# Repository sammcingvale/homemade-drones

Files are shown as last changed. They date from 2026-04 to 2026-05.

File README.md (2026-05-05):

# homemade-drones

at-home, at-scale drone swarms. drones, lots of drones.

## repo layout

```
drone-program/
├── docs/                    # cross-build documentation
│   ├── design-principles.md
│   ├── safety-checklist.md
│   └── repo-conventions.md
├── tools/                   # scripts shared across builds
├── hardware-library/        # reusable parts catalog, kits, CAD
│   ├── parts-catalog/       # abstract part specs + ranked SKUs + reorder guidance
│   └── kits/                # packing lists for field/bench operations
└── builds/
    ├── v1/                  # build #1 — learning vehicle, fly ASAP
    │   ├── README.md        # build summary + status
    │   ├── requirements.md  # frozen requirements doc for this build
    │   ├── bom.md           # bill of materials (references catalog by cat-NNN)
    │   ├── tooling.md       # tools required to assemble
    │   ├── cad/             # 3D models — one folder per part
    │   ├── firmware/        # ArduCopter firmware + parameters
    │   ├── assembly/        # assembly notes + build photos
    │   ├── flight-logs/     # per-flight logs and post-flight notes
    │   └── post-mortem.md   # written after build is retired
    ├── v2/                  # (future)
    └── v3/                  # (future)
```

## build status

| build | goal | status | flight count |
|---|---|---|---|
| v1 | L1 autonomy — GPS waypoint mission | 🟡 in design | 0 |
| v2 | L1+ — geofence, optical-flow position hold | ⚪ not started | — |
| v3 | L2 — vision-based autonomy, GPS-denied | ⚪ not started | — |
| v4 | L3 — swarm coordination | ⚪ not started | — |

## per-build philosophy

each `builds/vN/` folder is a complete, self-contained snapshot of that drone build. requirements, BOM, CAD, firmware, and flight logs live with the build they belong to. when v2 starts, we copy v1's contents as a starting point and iterate — old builds stay frozen for reference and post-mortem analysis.

components that prove themselves across multiple builds graduate to `hardware-library/`.

## getting started

if you're cloning fresh:
1. read `docs/design-principles.md` and `docs/safety-checklist.md`.
2. open the most recent active build's `README.md` for current status.
3. never skip a gate in the test plan. failed gate → debug, don't push through.

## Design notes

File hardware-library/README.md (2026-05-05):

# hardware-library/

Cross-build hardware design knowledge: parts catalog, kits, and (eventually) reusable CAD components.

## Subfolders

```
hardware-library/
├── parts-catalog/    # Abstract part specs + ranked SKU lists + reorder guidance
├── kits/             # Packing lists for field/bench operations
└── (cad/)            # Reusable CAD components — populated when parts graduate from a build
```

## What lives here vs. what doesn't

This folder holds **design knowledge** that spans builds: which parts are acceptable, why we picked them, what they're for. It's version-controlled, infrequently mutated, and tied to the project.

It deliberately does **not** hold operational state — current on-hand counts, order history, who-touched-what-when. Those live outside the repo and are owned by tooling that operates across multiple projects.

## Catalog vs. BOM

- **Catalog** (`parts-catalog/`): "what parts are acceptable for builds in this project, ranked by preference."
- **BOM** (`builds/vN/bom.md`): "what was procured for this specific build, at what price, on what date."

A build's BOM references catalog entries by ID. The catalog is the abstract spec; the BOM is the concrete procurement record for one build.

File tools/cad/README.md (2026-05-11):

# CAD toolchain

We use [CadQuery](https://cadquery.readthedocs.io/) (Python) for parametric models. `.py` files are the source of truth; STEP and STL are exported artifacts.

## Why CadQuery

- Plain-text source → diff-friendly, branch-mergeable, AI-editable.
- Parametric: every part exposes a single block of variables at the top of its `.py`.
- Free, no account, no licence keys.
- STEP export is reusable in Fusion 360 / OnShape / FreeCAD if a part graduates to a more complex workflow later.

## One-time setup

CadQuery's OCP backend needs Python 3.11. The repo root keeps a venv at `.venv/`.

```bash
# from the repo root
uv venv --python 3.11 .venv
uv pip install --python .venv/bin/python -r tools/cad/requirements.txt
```

`.venv/` is gitignored.

## Generating exports

Each part's `.py` is runnable directly. From the repo root:

```bash
.venv/bin/python builds/v1/cad/gps-mast/gps-mast-v1.py
```

The script writes `*.step` and `*.stl` next to itself. Re-run after any geometry edit.

## What gets committed

| Committed | Source / generated |
|---|---|
| `<part>-v<n>.py` | source — hand-edited |
| `<part>-v<n>.step` | generated — kept in git so reviewers don't need a Python env |
| `<part>-v<n>.stl` | generated — convenience export |
| `<part>-v<n>.3mf` | generated in Bambu Studio with slicer profile baked in |
| `<part>-v<n>.slicer-profile.json` | exported from Bambu Studio after tuning |
| `README.md`, `notes.md` | hand-written |

`.3mf` and the slicer profile come from Bambu Studio, not the Python script — they capture print settings, not just geometry.

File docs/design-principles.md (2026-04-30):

# design principles

cross-build principles that apply to every drone build.

## scaled-manufacturing posture (from v1)

even though v1 is a learning vehicle, we bake in habits that scale.

- **no exotic sourcing.** every part available from ≥2 distributors. eventually target US-based distributors and vertically integrated where possible.
- **no hand-tuned firmware per unit.** firmware flash is a script. parameters are version-controlled per airframe revision, not per serial number.
- **print times scale.** no part exceeds 4h on a stock 0.4mm nozzle.
- **standard fasteners.** M3 for structure, M2 for electronics. single thread pitch only.
- **connector discipline.** XT60 battery, MR30 / PH 2.0 accessories, ELRS-standard pinout receiver.
- **replaceable wear items.** props, motors, FC swappable in <10 min field repair.
- **identical units.** two airframes of the same revision must be functionally interchangeable.

## build progression philosophy

| build | bias |
|---|---|
| v1 | **fly ASAP.** hybrid (purchased CF + printed accessories). standard parts, well-documented stack. |
| v2 | **iterate on print.** move structural parts to printed PA-CF. tighten assembly time. |
| v3 | **add autonomy depth.** companion computer, vision stack, GPS-denied. |
| v4 | **multiply.** swarm comms, coordination. optimize manufacturability. |

## test gating discipline

every build runs through the same 10 gates (G1–G10). a failed gate is always a debug step, never a "we'll fix it later."

## versioning

- requirements doc: `requirements.md` per build, with a `## changelog` section at the bottom.
- CAD: `/cad/<part>/v<n>/` — increment `n` for any geometry change. old versions stay.
- firmware params: `/firmware/params/<airframe_serial>.params` — committed before each flight.
- flight logs: `/flight-logs/<YYYY-MM-DD>_<flight_id>/` — bin file, telemetry, post-flight notes.

## decision logs

substantive design decisions get logged. format: short markdown file in `/docs/decisions/` titled `NNNN-decision-name.md` with date, context, options considered, decision, consequences. inspired by ADRs (Architecture Decision Records).

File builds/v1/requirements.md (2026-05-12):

# Drone Requirements — v1 build

**Version:** v0.3
**Status:** LOCKED for parts ordering
**Build target:** v1 (learning vehicle)
**Constraint:** flight-capable in <7 days from parts arrival
**Long-term:** scaled printing + assembly of identical units, eventually swarm-coordinated

---

## 0. Locked decisions

| # | Decision | Value | Status |
|---|---|---|---|
| 0.1 | Frame size (prop diameter) | 5" | LOCKED |
| 0.2 | Sub-250g target? | No (v1). Will target lower weights in subsequent builds. | LOCKED |
| 0.3 | Indoor / outdoor / both | Outdoor, GPS-available | LOCKED |
| 0.4 | Structural main plate | Purchased CF (Source One V5). Print accessories. | LOCKED |
| 0.5 | Autonomy scope for v1 | L1 — GPS waypoint mission (see §2.5) | LOCKED |
| 0.6 | Companion computer in v1? | No — defer to v3 | LOCKED |
| 0.7 | Onboard pilot-view video link? | **No, in any build.** Cameras allowed only for autonomy/mission data inputs. | LOCKED |
| 0.8 | FC firmware | ArduCopter (latest stable, ≥4.5) | LOCKED |
| 0.9 | Ground station | Mission Planner on Windows (used Toughbook CF-54) | LOCKED |
| 0.10 | Radio (TX) | RadioMaster Pocket (ELRS built-in) | LOCKED |
| 0.11 | Number of airframes for week 1 | 1 | LOCKED |
| 0.12 | Jurisdiction | US (FAA) | LOCKED |

---

## 1. Design principles

See `docs/design-principles.md` for cross-build principles. Build-specific notes:

- v1 prioritizes **time-to-flight** over manufacturability or performance.
- v1 uses standard, well-documented components so help is one Google query away.
- v1 builds the workflow: order → assemble → flash → bench-test → tethered → free flight → autonomous. Same workflow scales to v2+.

---

## 2. Mission profile

| Parameter | Value | Notes |
|---|---|---|
| Operating environment | Outdoor, open field, daylight | Park adjacent to operator |
| GPS available | Yes | Drives autonomy stack |
| Operating altitude (AGL) | <120m (US Part 107 ceiling) | v1 mission flies at 5m |
| Range from operator | <500m line-of-sight | ELRS easily covers |
| Endurance per sortie | 8–12 min hover max | Sets battery sizing |
| Mission payload (carried) | None | LOCKED |
| Speed envelope | 0–20 m/s typical | v1 mission flies at 2 m/s |
| Wind tolerance | <8 m/s sustained | Hard ceiling on 5" airframe |
| Weather | Dry only | No conformal coating in v1 |
| Day/night | Day only | No nav lights in v1 |
| Temperature | 0°C to 35°C ambient | LiPo limits |

**v2+ deferred:** rain/dust ingress, night ops, BVLOS, cold-soak, payload drop.

---

## 2.5 Autonomy roadmap

| Build | Level | Capability | Stack additions |
|---|---|---|---|
| **v1** | **L1 — Pre-programmed mission** | **GPS waypoint mission, manual abort, auto RTH on failsafe** | **ArduCopter AUTO mode, Mission Planner mission upload** |
| v2 | L1+ | Geofence, smart RTH, optical-flow position hold | + downward optical flow sensor |
| v3 | L2 — Reactive | Obstacle avoidance, GPS-denied hover (VIO), dynamic re-plan | + companion computer (RPi 5 / Jetson Orin Nano), ROS2, depth camera |
| v4 | L3 — Multi-vehicle | Swarm: formation, leader-follow, distributed task allocation | + mesh comms, ROS2 DDS, coordination logic |

### v1 mission spec

- **Pattern:** 4-waypoint square, 18m × 18m (≈ 20 yd × 20 yd)
- **Altitude:** 5m AGL, constant
- **Cruise speed:** 2 m/s (slow, observable, easy to abort)
- **Sequence:** Manual arm → AUTO-takeoff to 5m → WP1→WP2→WP3→WP4 (CCW from takeoff) → AUTO-RTH → AUTO-land
- **Total flight time:** ~90s

### v1 failsafe matrix

| Trigger | Response |
|---|---|
| RC link loss | RTH, then land |
| Battery <30% | RTH |
| Battery <20% | Land at current position |
| GPS loss >5s | Land at current position |
| Geofence breach | RTH to fence center |
| Pilot kill switch | Disarm immediately (motors stop) |

Failsafes configured in ArduCopter parameters (`firmware/params/v1-001.params`) and version-controlled.

---

## 3. Vehicle spec

| Slot | Spec |
|---|---|
| Class | Quadcopter, X-config |
| Frame | Source One V5 5" Base Kit |
| Motor-to-motor diagonal | 220mm |
| AUW target | 600–700g w/ 4S 1500mAh |
| AUW max (structural) | 900g |
| FC stack mounting | 30.5×30.5mm |

---

## 4. Propulsion

| Slot | Spec | Selection |
|---|---|---|
| Motors | 2207, ~1950KV (4S) | EMAX ECO II 2207 1900KV ×4 |
| Props | 5×4.3×3 (5-inch tri-blade) | HQProp T5x4.3x3 ×4 sets |
| ESC | 4-in-1, 55A, BLHeli_S | Bundled with FC stack |

Any 2207 motor in 1750–2000KV works. EMAX ECO II picked for cost + ubiquity. Don't agonize.

---

## 5. Power

| Slot | Spec | Selection |
|---|---|---|
| Chemistry | LiPo | |
| S-count | 4S | |
| Capacity | 1500 mAh | ~10 min hover |
| C-rating | 100C | |
| Connector | XT60 | |
| Charger | ToolkitRC M7 (built-in AC) | |
| Storage | LiPo bag, 3.8V/cell storage charge | |
| Field kit | 4× packs minimum | |

---

## 6. Avionics

| Slot | Spec | Selection | Notes |
|---|---|---|---|
| Flight controller + ESC | F4/H7 stack, 30.5×30.5mm | Holybro Kakute H7 v1.5 + Tekko32 F4 50A ESC | ArduCopter target `KakuteH7` (4.2.0+). SpeedyBee F405 V4 was the original choice; flipped 2026-05-11 after it went OOS at all distributors. |
| FC firmware | ArduCopter ≥4.5 | | Board ships with Betaflight — first flash via DFU |
| IMU | ICM-42688P | Onboard FC | |
| Barometer | Onboard FC | | |
| Magnetometer | External (on GPS module) | Bundled with M10Q-5883 GPS | NEVER use FC-internal mag |
| GPS + compass | u-blox M10 + QMC5883L | Matek M10Q-5883 | Mount on printed mast ≥80mm |
| Current/voltage sensor | Onboard ESC | | Required for ArduPilot battery failsafe |

**EMI / RF notes:**
- GPS mast ≥80mm. Non-negotiable.
- Magnetometer ≥150mm from high-current wires (mast-mounted solves this).
- ELRS RX antennas at 90° to each other, both extending past frame edges.
- Carbon fiber blocks RF — antennas must clear the frame in line-of-sight to operator.

---

## 7. Comms

| Link | Purpose | Selection | Range |
|---|---|---|---|
| RC control | Pilot input, failsafe | RadioMaster Pocket (ELRS) ↔ BetaFPV ELRS Lite RX | 2km+ |
| Telemetry | MAVLink ↔ Mission Planner | Holybro SiK Radio 915MHz pair | 1km+ |
| Video | **Not installed** | — | — |
| Swarm mesh | **Deferred to v4** | — | — |

---

## 8. Manufacturing — print plan

### v1 printed parts

| Part | Filament | Print time | Notes |
|---|---|---|---|
| Canopy / top plate | PETG | ~2h | Houses GPS, RX, telem |
| GPS mast (≥80mm) | PETG | ~30min | RF-transparent |
| Antenna mounts (×2) | TPU 95A | ~20min ea | Soft, won't snap |
| Battery tray + strap loop | PETG | ~1h | |
| Motor soft-mounts (×4) | TPU 95A | ~30min total | IMU vibration isolation |
| Standoffs (M3, ×4) | TPU 95A or aluminum | ~15min | Either works |

**Total print time: ~5h** on a Bambu P2S, single bed plate.

### Filament strategy

| Filament | Use case | v1 Required |
|---|---|---|
| **PETG** | Non-structural rigid parts | ✅ |
| **TPU 95A** | Soft mounts, antenna tubes | ✅ |
| **PA-CF** | Structural (v2+) | ❌ |
| **ASA** | Outdoor exposed parts (v2+) | ❌ |
| **PLA** | ❌ Do not use | ❌ |

### Printer config

- Bambu Lab P2S, AMS 2 Pro
- Stock 0.4mm nozzle for v1 (PETG + TPU only)
- Hardened nozzle deferred until v2 (when PA-CF enters)

### Print process discipline

- All parts version-controlled under `cad/<part>/` per repo conventions.
- STEP is source of truth. STL/3MF exported from STEP.
- Slicer profile committed alongside model.
- Print orientation noted in `notes.md` per part.
- No supports on production parts — design them out.

---

## 9. Regulatory & safety

US, FAA jurisdiction.

| Item | Requirement | Status |
|---|---|---|
| FAA recreational registration | Required >250g | ✅ Completed 2026-05-11 |
| Remote ID | Required >250g since Sept 2023 | ArduPilot built-in broadcast |
| Part 107 | Commercial only | Not needed |
| Flight area | TRUST cert + Class G airspace | ✅ TRUST completed 2026-05-11; airspace verified per flight |
| LAANC | Controlled airspace only | Avoid for v1 |
| Insurance | Optional | AMA membership recommended |

Safety procedures: see `docs/safety-checklist.md`.

---

## 10. Test plan — gates

Each gate must pass before next attempted. Failed gate → debug, don't push through.

| Gate | Pass criterion | Tools | Estimated day |
|---|---|---|---|
| G1: Bench power-on | FC boots, no smoke, no overheat | Smoke stopper, IR thermometer | Day 4 |
| G2: RX bind + arming | All channels move correctly, arming gate passes | Mission Planner | Day 4 |
| G3: Motor direction + ESC cal | All 4 motors spin correct direction, DSHOT telem healthy | Props OFF | Day 5 |
| G4: IMU + compass cal | Cal completes, mag interference <30% | MP cal screens | Day 5 |
| G5: GPS lock | ≥10 sats, HDOP <1.5, position holds within 2m at rest | Open sky, 5+ min | Day 5 |
| G6: Tethered hover | Stable hover, no oscillation, throttle response linear | 2m tether to ground anchor | Day 6 |
| G7: Free hover (manual STABILIZE) | 30s stable hover at 2m, manual landing | Open field, observer | Day 6 |
| G8: GPS position hold (LOITER) | Holds within 3m for 60s | | Day 6 |
| G9: RTH test | Triggers RTH, returns within 5m of takeoff, lands | Manual abort ready | Day 7 |
| **G10: AUTO mission** | **4-waypoint 18m square, autonomous start to finish** | **MP mission upload** | Day 7 |

**G10 = week-1 target.** See `bom.md` for parts and `tooling.md` for required tools.

---

## 11. v2+ deferred items

Cataloged so we don't lose them.

- Printed structural main plate + arms in PA-CF
- Conformal coating for moisture resistance
- Companion computer (RPi 5 / Jetson Orin Nano) for vision-based autonomy
- VIO / SLAM stack (ROS2 + PX4 / ArduPilot + VINS-Fusion)
- Obstacle avoidance sensors (ToF, depth camera)
- Mesh comms for swarm
- Multi-vehicle coordination
- Night ops
- Payload mounts / data collection
- Field-swappable battery (tool-less)
- Production jig for assembly time-tracking

---

## 12. Bill of materials

See `bom.md` (in this folder).

---

## 13. Tooling

See `tooling.md` (in this folder).

---

## Changelog

- **v0.3** — Locked all open decisions from Section 13. Added 0.7 (no pilot-view video, ever), 0.8–0.12 (firmware, ground station, radio, build count, jurisdiction). Specified concrete SKUs in §4–§7. Added day-by-day estimates to test plan. Author: Claude. Status: LOCKED.
- **v0.2** — Added §2.5 autonomy roadmap, v1 mission spec, failsafe matrix. Locked 0.5. Removed crash-survivability driver.
- **v0.1** — Initial draft.

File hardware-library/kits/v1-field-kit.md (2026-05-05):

# v1 Field Kit

What to bring to a field flight session with the v1 airframe.

## Aircraft + power

- [ ] v1 airframe (1×)
- [ ] LiPo packs, charged: 4× (cat-008)
- [ ] Spare LiPo: +1× if available
- [ ] LiPo bag (transport)
- [ ] Battery straps: 2× spare

## Spare parts (for in-field repair)

- [ ] Spare props: 8× individual props (cat-004) — 2 full sets
- [ ] Spare motor: 1× (cat-003)
- [ ] Spare M3 SHCS, 12mm + 16mm: ~10 each (cat-011)
- [ ] Spare M3 nyloc nuts: ~10 (cat-012)

## Tools (mechanical)

- [ ] 2.5mm hex driver (Wera)
- [ ] M5 nut driver / rubber prop wrench
- [ ] Side cutters
- [ ] Tweezers
- [ ] Loctite 243 (small bottle for motor screw replacement)

## Tools (electrical / diagnostic)

- [ ] Multimeter
- [ ] USB cable (USB-C, for FC reflash if needed)
- [ ] Smoke stopper (XT60 inline) — for any post-crash power-up

## Ground station

- [ ] Toughbook (charged)
- [ ] SiK ground radio (915MHz USB-A)
- [ ] USB-A extension cable
- [ ] RadioMaster Pocket transmitter (charged)
- [ ] USB-C cable for TX charging (optional, for long sessions)

## Safety + admin

- [ ] FAA registration card (or printout)
- [ ] TRUST certificate (printout or phone screenshot)
- [ ] Phone with B4UFLY app
- [ ] Sand bucket or fire extinguisher (Class D)
- [ ] First aid kit (small)
- [ ] Eye protection (cheap safety glasses)
- [ ] Sunshade for laptop (folding cardboard works fine)

## Logging

- [ ] Notebook + pen for in-field observations
- [ ] Phone for build/flight photos

---

## Pack-out workflow

Before leaving the workshop:

1. Charge all LiPos to **flight charge** (4.20V/cell). Confirm cell balance ≤0.02V deviation per pack.
2. Run the airframe through the safety checklist (`docs/safety-checklist.md` → Pre-flight).
3. Check the weather. <8 m/s sustained wind is the hard ceiling.
4. Verify flight area on B4UFLY.
5. Pack this kit. Tick boxes physically.

## Pack-in workflow

After returning from the field:

1. Set all LiPos to storage charge (3.80V/cell) within 24 hours.
2. Visual inspection of airframe — log any damage in build's `flight-logs/<latest>/notes.md`.
3. Note anything used or damaged in the field for follow-up restocking.
4. Note any tools left at the field site (it happens).

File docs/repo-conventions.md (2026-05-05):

# Repo Conventions

Lightweight rules so that files end up in predictable places.

## Naming

- Files and folders: lowercase, hyphenated. `gps-mast`, not `GPS_Mast` or `gpsMast`.
- Markdown extensions: `.md`.
- CAD: `<part>-v<n>.step`, `<part>-v<n>.3mf`. STEP is the source of truth; export STL/3MF from STEP.
- Slicer profiles: `<part>-v<n>.slicer-profile.json` next to the model.
- Firmware params: `<airframe-serial>.params` (e.g. `v1-001.params`).
- Flight logs: `<YYYY-MM-DD>_<flight-id>_<short-description>/` (e.g. `2025-12-04_001_first-tethered-hover/`).

## CAD versioning

For every printed part:
```
builds/v1/cad/<part-name>/
├── README.md                    # what the part does, design intent
├── <part-name>-v1.step          # source of truth
├── <part-name>-v1.3mf           # slicer-ready (with profile baked in)
├── <part-name>-v1.stl           # exported, optional
├── <part-name>-v1.slicer-profile.json
└── notes.md                     # print orientation, supports, lessons
```

Increment version on any geometry change. **Never edit a versioned file in place** — copy to v2 and edit there.

## Commits

- Imperative, present tense: "add v1 GPS mast STEP", not "added" or "adds".
- Reference the build in the subject if scoped to one: `[v1] update bom — switch to T-Motor F40`.
- One logical change per commit. Don't bundle "fix typo" with "redesign canopy".

## Branches

- `main` is always known-good. Pushing broken code there delays the next flight.
- Work on `vN/<short-feature>` branches. Merge to main when the change has been validated (printed and fitted, or flashed and tested).

## Catalog entries

`hardware-library/parts-catalog/cat-NNN-name.md` files follow the format documented in `hardware-library/parts-catalog/README.md`. Key rules:

- `cat-NNN` IDs are immutable. Don't renumber.
- A catalog entry is design knowledge: abstract spec, ranked SKUs, reorder guidance, last-known prices.
- Update `Last verified` whenever prices or SKU rankings change.

## What to commit, what not to

| Commit | Don't commit |
|---|---|
| STEP, 3MF, slicer profile | Slicer scratch files, autosaves |
| Firmware `.apj` actually flashed (under `firmware/flashed/`) | Random `.hex` downloads |
| Param files used for flight | Mission Planner cache |
| Flight log `.csv` and `.tlog` | Raw `.bin` files (>10MB; large + recoverable from .csv) |
| Build photos in `assembly/photos/` | Anything containing API keys, GPS home coords for your house |

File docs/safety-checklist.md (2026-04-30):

# safety checklist

read before every assembly session and every flight session. violation of any rule = stop work.

## workshop / assembly

- [ ] smoke stopper between battery and PDB on first power-up of any airframe revision.
- [ ] multimeter checks: continuity on all solder joints, no shorts between VCC and GND, before first power-up.
- [ ] props OFF for all bench tests (G1–G5). props go on at G6 (tethered hover).
- [ ] LiPo bag in use any time a battery is connected and unattended (charging, storage, transport).
- [ ] Class D fire extinguisher or sand bucket within reach during any LiPo charging.
- [ ] no charging unattended. period.
- [ ] eye protection during any soldering or first power-up.
- [ ] soldering iron returned to stand between joints, not laid on bench.
- [ ] storage charge LiPos to 3.8V/cell if not flying within 48h.

## pre-flight

- [ ] FAA registration current (>250g recreational drones).
- [ ] remote ID broadcasting (FC firmware-based or external module).
- [ ] TRUST certificate on operator.
- [ ] flight area is Class G airspace (verified with B4UFLY app).
- [ ] no people, animals, or property inside the planned flight envelope + 20m buffer.
- [ ] wind <8 m/s sustained for 5" airframe.
- [ ] battery storage voltage checked, packs are at 4.20V/cell ±0.05V before flight.
- [ ] props inspected — no nicks, cracks, or imbalance.
- [ ] motors free of debris, spin freely by hand.
- [ ] all M3 frame screws thread-locked and tight.
- [ ] GPS lock acquired (≥10 sats, HDOP <1.5) before arming for autonomous mission.
- [ ] failsafe behavior verified by simulating RC loss before any autonomous flight.
- [ ] geofence configured and uploaded.
- [ ] kill switch tested on the bench before flight.
- [ ] observer present and aware of flight plan.

## in-flight

- [ ] pilot keeps hand on kill switch for entire flight.
- [ ] autonomous mode never engaged on first flight of a build — always start in STABILIZE/LOITER and earn AUTO.
- [ ] abort criteria pre-agreed: any unexpected behavior → switch to STABILIZE → land manually.

## post-flight

- [ ] battery disconnected before approaching the airframe.
- [ ] flight log downloaded and saved to `/builds/vN/flight-logs/<date>_<id>/` before next flight.
- [ ] visual inspection: motors, props, frame, electronics for damage.
- [ ] battery temp checked — if >50°C, allow to cool before recharging.

## after a crash

- [ ] **do not recharge the crash battery for 30 min.** watch for puffing/smoke.
- [ ] photograph crash site and damage before moving anything.
- [ ] record crash conditions in flight log directory (`crash-notes.md`).
- [ ] disposition the LiPo: if puffed, dented, or hot — saltwater discharge + safe disposal. don't reuse.
- [ ] no further flights until root cause identified and documented.

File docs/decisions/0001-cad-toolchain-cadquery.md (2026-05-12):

# 0001 — CAD toolchain: CadQuery

**Date:** 2026-05-05
**Status:** Accepted
**Applies to:** all builds (cross-cutting)

## Context

v1 needs 5–6 printed parts (gps-mast, antenna mounts, battery tray, motor soft-mounts, canopy, standoffs). Future builds will reuse and extend the same parts library. We need a CAD workflow that:

- Is version-controllable in git with meaningful diffs (not opaque binaries).
- Survives "no exotic sourcing" — the toolchain itself should be free, open, no account, no licence keys, no vendor lock-in.
- Plays well with branch-merge workflows (we'll have many overlapping airframe revisions).
- Can be edited by both humans and AI assistants without a GUI.
- Exports a portable interchange format (STEP) so any part can be opened later in Fusion 360, OnShape, or FreeCAD if needed.
- Is parameterized so a single `WIDTH = 38.0` change re-exports the whole part — supports the scaled-manufacturing posture from `docs/design-principles.md`.

## Options considered

| Tool | Source format | Pros | Cons |
|---|---|---|---|
| **CadQuery (Python)** | `.py` (plain text) | Diff-friendly, free, no account, AI-editable, STEP/STL export, real parametric, scriptable | OCP backend pins us to Python 3.10–3.11 (not the latest Python); learning curve if unfamiliar |
| Autodesk Fusion 360 | `.f3d` (binary) | Polished UI, large user base, plenty of tutorials | Binary source → useless in git, requires Autodesk account, free tier may shrink |
| OnShape | cloud doc | Browser-based, real Git-like document versioning | Cloud-dependent, requires account, can't grep the design from a terminal |
| FreeCAD | `.FCStd` (zipped XML, semi-text) | Free, offline, open source | Diffs are noisy, file format historically unstable across versions, GUI required |
| OpenSCAD | `.scad` (plain text) | Diff-friendly, scriptable, free | Mesh-only output, no STEP export → poor reusability for parts that may graduate to other tools |

## Decision

**CadQuery 2.7 in a Python 3.11 venv at the repo root.**

- `.py` files are the source of truth.
- `.step` and `.stl` are exported next to the `.py` and committed so non-Python reviewers can inspect geometry without standing up the toolchain.
- `.3mf` and slicer profile JSON come from Bambu Studio after slicer tuning — they capture print settings, not just geometry.
- Toolchain setup documented in `tools/cad/README.md`. One-time: `uv venv --python 3.11 .venv && uv pip install -r tools/cad/requirements.txt`.

## Consequences

**Positive:**
- Plain-text CAD source means PRs show real diffs and merges work as expected.
- AI assistants can edit geometry directly.
- Parametric block at the top of each part's `.py` lets us flip `BASE_W = 38.0` once and re-export — directly supports the scaled-manufacturing posture.

**Negative:**
- Anyone new joining the build needs the venv set up before they can re-export. Mitigated by committing `.step` and `.stl` so they can read geometry without running anything.
- CadQuery's GUI story is weak. We use the CLI + Bambu Studio for visual review; an SVG preview is exported per part as a sanity-check artifact.

**Known gotcha (worth surfacing here so it doesn't get rediscovered):** `cq.exporters.export(..., '.stl')` mutates the underlying `TopoDS_Compound`'s bounding box (the STL tessellation gets attached). Always read `mast.val().BoundingBox()` *before* the STL export, otherwise reported dimensions inflate by ~1.5 mm per axis. See `builds/v1/cad/gps-mast/gps-mast-v1.py` for the established order: read stats first, export second.

## Validation

First part shipped (`builds/v1/cad/gps-mast/gps-mast-v1.py`, 2026-05-05) — clean STEP and STL export, 38×38×100 mm bounding box matching the parametric inputs. Workflow works end-to-end.

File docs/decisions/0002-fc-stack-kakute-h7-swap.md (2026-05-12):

# 0002 — FC stack swap: SpeedyBee F405 V4 → Holybro Kakute H7 v1.5

**Date:** 2026-05-11
**Status:** Accepted
**Applies to:** build v1 (and downstream until re-evaluated)

## Context

v1 BOM originally specified **SpeedyBee F405 V4 BLS 55A 30×30 Stack** as the rank-1 flight controller stack (catalog `cat-002`). Picked for cost (~$94), ubiquity in the ArduCopter community, well-documented DFU flash procedure, and broad distributor coverage.

During the procurement push on 2026-05-10/11, the V4 was OOS at every distributor we'd cataloged: GetFPV, Pyrodrone, Amazon (SpeedyBee storefront). No restock dates available. Holding the build for an unknown duration would directly violate OKR #1 (fly ASAP).

We had three options:

1. **Wait** for SpeedyBee F405 V4 restock at any distributor. Open-ended slip.
2. **Drop to SpeedyBee F405 V3** (the predecessor revision, same family, same firmware target family). Cheaper (~$80–90) and a direct drop-in. Stock also intermittent.
3. **Switch SKU to Holybro Kakute H7 v1.5 + Tekko32 F4 50A ESC stack.** Different vendor, different MCU (H7 instead of F405), different ESC firmware family (AM32 instead of BLHeli_S), $124.99 in stock at Holybro-direct.

## Decision

**Switch to Holybro Kakute H7 v1.5 + Tekko32 F4 4-in-1 50A ESC stack.** Rank-1 in cat-002 is updated to Holybro-direct at $124.99. SpeedyBee F405 V4 stays at rank-2 and V3 at rank-3 as fallbacks for future builds.

## Why this over option 1 (wait)

OKR #1 is fly ASAP. The whole v1 build was sequenced for time-to-G10 — waiting on a single SKU with no ETA is a procedural failure. The procurement research had already documented multiple acceptable substitutes; choosing one is exactly what the catalog's ranked-SKU structure is built for.

## Why this over option 2 (SpeedyBee F405 V3)

V3 was also intermittent at distributors, with the same OOS pattern as the V4. Switching to V3 was a sideways move with the same supply-chain risk. The Kakute H7 was confirmed in stock at the manufacturer directly on the day of order.

## Why this over other ArduCopter-supported 30×30 stacks

Kakute H7 is on the [ArduPilot supported autopilots list](https://ardupilot.org/copter/docs/common-autopilots.html) explicitly (target `KakuteH7`, ≥4.2.0). Holybro is an ArduPilot partner — first-party support, well-documented integration. We just successfully ordered the GPS module from Holybro-direct (cat-005), so the supply line is already open.

Spec check vs. the cat-002 abstract spec — every requirement met or exceeded:

| Requirement | Kakute H7 v1.5 + Tekko32 50A |
|---|---|
| 30.5×30.5mm mounting | ✅ identical pattern |
| ≥F405 MCU | ✅ STM32H743 (H7, exceeds spec) |
| ICM-42688P gyro | ✅ |
| Onboard baro | ✅ |
| 4-in-1 ESC ≥45A continuous | ✅ 50A |
| BLHeli_S / BLHeli_32 / AM32 | ✅ AM32 (modern open-source ESC firmware) |
| DSHOT600, bidi-DSHOT | ✅ default in AM32 |
| USB-C | ✅ |
| Onboard current sensor | ✅ |
| Dual BEC (5V + 9V) | ✅ 5V 2A + 9V 3A |

## Consequences

**Positive:**
- Build unblocked the day the decision was made.
- H7 MCU gives meaningful headroom for v2+ autonomy work (companion computer offload, more peripherals, more telemetry rate). Less likely to be the limiting factor when v2 work starts.
- AM32 ESC firmware is the modern successor to BLHeli_32 — open-source, actively maintained, full DSHOT support.
- Holybro vendor concentration: cat-005 (GPS) and cat-002 (FC) both sourced from Holybro-direct. One fewer shipping bill.

**Negative — accepted:**
- **+$31/unit (+33%)** vs SpeedyBee V4. With one spare in the BOM: +$62 total. New v1 total ~$1,653 vs $1,591. Manageable.
- **Documentation drift.** Most ArduCopter community howtos for 5" builds reference SpeedyBee F4 or Matek boards. Kakute H7 docs exist (Holybro's own + ArduPilot wiki) but the Stack Overflow / Reddit population is smaller. Mitigated by Holybro being an AP partner.
- **First-flash path may differ.** SpeedyBee ships with Betaflight (requires DFU + STM32CubeProgrammer). Kakute may ship blank, with ArduPilot bootloader, or with Betaflight depending on the SKU's run. `builds/v1/firmware/README.md` now branches on receipt to handle whichever state the board is in.
- **GPS cable will still need clip + resolder.** Same situation as with the V4 — Holybro M10 V2 connector and Kakute H7 GPS port are both standard Holybro pinouts but not always wired matching. Already flagged in cat-005 and BOM outstanding-flags.
- **Vendor concentration risk.** Holybro-direct is now single-source for two key items. If Holybro warehouse goes down or international shipping breaks, both items stall. Worth watching at v2 BOM time.

## Reversibility

High. cat-002 still lists the SpeedyBee V4 as rank-2 and V3 as rank-3. If the Kakute proves problematic (community support, parts availability, ESC quirks), switching back to a SpeedyBee F405 SKU is a one-line BOM change + firmware target rename. Spare FC purchase decision should weigh this.

## Follow-up actions

- [x] Update cat-002 (`hardware-library/parts-catalog/cat-002-fc-stack-30x30.md`)
- [x] Update BOM (`builds/v1/bom.md` — version bumped to v1.2)
- [x] Update firmware flash procedure (`builds/v1/firmware/README.md`)
- [x] Update requirements.md §6 vehicle spec table
- [ ] Decide whether to order the FC spare at the new price (~$125 vs $94). Defer until after G2 (initial bench bring-up) succeeds.
- [ ] On receipt: verify what firmware is on the Kakute board, choose the appropriate flash path.

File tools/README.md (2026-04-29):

# tools/

Cross-build scripts and utilities.

Empty for v1. Candidates as they emerge:

- `flash-firmware.sh` — automate ArduCopter flash via DFU + STM32CubeProgrammer CLI.
- `upload-mission.py` — pymavlink-based mission upload for repeatable test patterns.
- `param-diff.py` — compare two `.params` files and produce a diff report.
- `log-convert.sh` — wrap mavlogdump for batch `.bin` → `.csv` conversion.
- `bench-test.py` — automated G1–G5 checks via MAVLink.

When something gets done by hand more than twice, it gets a script here.

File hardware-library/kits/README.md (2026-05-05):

# Kits

Packing lists for specific operations. A kit is a *checklist of what to bring*, useful when going to the field or starting a build session.

## Available kits

| Kit | Purpose |
|---|---|
| `v1-field-kit.md` | What to bring to a field flight session for the v1 airframe |

## When to add a new kit

When you find yourself packing the same set of stuff twice. Examples that may emerge:

- `v1-soldering-bench.md` — what should be on the bench when working on v1 electronics
- `crash-recovery.md` — what to bring when retrieving a crashed airframe
- `multi-airframe-field.md` — when running 2+ airframes in the same session

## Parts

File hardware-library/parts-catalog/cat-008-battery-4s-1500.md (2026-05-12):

# LiPo Battery — 4S 1500mAh

**Catalog ID:** cat-008
**Status:** active
**Last verified:** 2026-05-11

## Abstract spec

- 4S configuration (14.8V nominal, 16.8V full, 14.0V land-now threshold per ArduCopter `BATT_CRT_VOLT`)
- 1300–1500 mAh capacity
- ≥100C continuous discharge rating
- XT60 connector
- JST-XH balance lead
- ≤180g
- ≤90 × 38 × 35 mm physical envelope (fits the printed battery tray at `builds/v1/cad/battery-tray/`). **Envelope loosened 2026-05-11** — the original ≤90 × 35 × 30 mm spec under-specified the rank-1 CNHL V2.0 130C pack (actual 76 × 36 × 33 mm), forcing a 1–3 mm interference on two axes. Envelope now reflects the verified rank-1 pack plus ~2 mm headroom.

## Ranked SKUs

| Rank | Mfr part | Vendor | URL | Unit price | Notes |
|---|---|---|---|---|---|
| 1 | CNHL Black Series V2.0 1500mAh 4S 130C XT60 | GetFPV | https://www.getfpv.com/cnhl-black-series-v2-0-130c-4s-lipo-battery-1500mah.html | $31.49 | in stock at GetFPV 2026-05-10. **130C strictly exceeds the spec floor.** Verified physical dimensions: 76 × 36 × 33 mm, 164 g (multi-distributor confirmation 2026-05-11). Replaces the V1 100C SKU which is no longer carried. |
| 2 | CNHL Black Series 1500mAh 4S 100C XT60 (V1, older) | CNHL US warehouse | https://cnhl-us.com/ (verify URL at order time) | ~$21 | cheaper, older V1 spec — only use if rank-1 unavailable |
| 3 | Tattu R-Line 1550mAh 4S 100C | GetFPV | https://www.getfpv.com/ | ~$32 | premium alternative; verify URL at order time |

## Reorder guidance

4 packs is the minimum for a useful field session. Reorder when at or below 4 healthy packs.

Suggested trigger: on hand ≤ 4. Suggested order qty: 4.

## Notes

- LiPos are consumables. **Lifespan: ~150–300 cycles** depending on care.
- Retire any pack that:
  - Has visible swelling
  - Shows >0.05V cell-to-cell imbalance after a full charge
  - Drops below 14.0V under hover load
  - Has been damaged in a crash (puffed, dented, hot)
- Retired packs: discharge to 0V via saltwater bath (24+ hours), then dispose at battery recycling drop-off.
- Storage: 3.8V/cell if not flying within 48h. Modern smart chargers do this automatically.
- Retired packs are written off as attrition; reorder accordingly.

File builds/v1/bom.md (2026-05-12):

# v1 — Bill of Materials

**Status:** Ordering in progress
**Version:** v1.2
**Last verified:** 2026-05-11
**Vendor policy:** GetFPV preferred → RDQ → mfr-direct → Amazon (non-flight only)

> **Note on freshness:** Vendors and prices change. Verify each line at order time using the linked catalog entry (which holds the ranked SKU list and last-known prices). After ordering, this file becomes a frozen procurement record.

> **Note on stock:** As of 2026-05-04, several core SKUs were OOS at GetFPV (frame, FC stack, motors). Verify stock or be prepared to fall back to rank-2 SKUs in each catalog entry.

---

## Airframe + electronics (per airframe)

| # | Catalog | Description | Qty | Unit (last seen) | Subtotal | Notes |
|---|---|---|---|---|---|---|
| 1 | [cat-001](../../hardware-library/parts-catalog/cat-001-frame-5in.md) | 5" frame (Source One V5) | 1 | $39 | $39 | TBS-branded at GetFPV preferred |
| 2 | [cat-002](../../hardware-library/parts-catalog/cat-002-fc-stack-30x30.md) | Kakute H7 v1.5 + Tekko32 F4 50A stack | 1 | $125 | $125 | ArduCopter `KakuteH7` target — SpeedyBee F405 V4 OOS, rank-1 promoted 2026-05-11 |
| 3 | [cat-003](../../hardware-library/parts-catalog/cat-003-motor-2207.md) | 2207 1900KV motors | 4 | $20 | $80 | Order set of 4 |
| 4 | [cat-004](../../hardware-library/parts-catalog/cat-004-prop-5in-tri.md) | 5×4.3×3 tri-blade props | 16 | $1 | $16 | 4 sets of 4 |
| 5 | [cat-005](../../hardware-library/parts-catalog/cat-005-gps-compass.md) | M10 GPS + compass (Holybro) | 1 | $45 | $45 | **Replaced Matek M10Q-5883 (EOL)** |
| 6 | [cat-006](../../hardware-library/parts-catalog/cat-006-rx-elrs-24ghz.md) | ELRS 2.4GHz RX (Flat V1.2) | 1 | $9 | $9 | Tower variant discontinued at BetaFPV; Flat V1.2 substituted 2026-05-11 (integrated SMD antenna in both — equivalent functionally) |
| 7 | [cat-007](../../hardware-library/parts-catalog/cat-007-telem-radio-915mhz.md) | SiK V3 915MHz pair, **100mW** | 1 pair | $60 | $60 | 100mW chosen — range margin sufficient |
| 8 | [cat-002](../../hardware-library/parts-catalog/cat-002-fc-stack-30x30.md) | Spare FC + ESC stack | 1 | $125 | $125 | Hedge against first-build solder mistakes |
| | | **Airframe + electronics subtotal** | | | **$499** | |

## Power & charging

| # | Catalog | Description | Qty | Unit | Subtotal | Notes |
|---|---|---|---|---|---|---|
| 9 | [cat-008](../../hardware-library/parts-catalog/cat-008-battery-4s-1500.md) | 1500mAh 4S 100C XT60 LiPo (CNHL Black) | 4 | $28 | $112 | Bought via GetFPV per vendor policy |
| 10 | (uncataloged) | ToolkitRC M7AC charger | 1 | $70 | $70 | One-time |
| 11 | (uncataloged) | LiPo charge/transport bag | 1 | $15 | $15 | One-time |
| 12 | (uncataloged) | Smoke stopper (XT60 inline) | 1 | $15 | $15 | One-time |
| | | **Power subtotal** | | | **$212** | |

## Radio (TX) — one-time

| # | Catalog | Description | Qty | Unit | Subtotal | Notes |
|---|---|---|---|---|---|---|
| 13 | (uncataloged — fixed asset) | RadioMaster Pocket (ELRS, M2 sticks) | 1 | $80 | $80 | EdgeTX firmware |
| | | **Radio subtotal** | | | **$80** | |

## Ground station — one-time

| # | Catalog | Description | Qty | Unit | Subtotal | Notes |
|---|---|---|---|---|---|---|
| 14 | (uncataloged — fixed asset) | Used Panasonic Toughbook CF-54 (daylight-readable screen, Win 10/11, ≥8GB) | 1 | $400 | $400 | eBay; verify "outdoor" variant |
| 15 | (uncataloged) | USB-A extender 6ft | 1 | $8 | $8 | |
| | | **Ground station subtotal** | | | **$408** | |

## Filament

| # | Catalog | Description | Qty | Unit | Subtotal | Notes |
|---|---|---|---|---|---|---|
| 16 | [cat-009](../../hardware-library/parts-catalog/cat-009-filament-petg.md) | PETG Basic, 1kg, black (Bambu) | 1 | $20 | $20 | Watch for sale ($13 recent) |
| 17 | [cat-010](../../hardware-library/parts-catalog/cat-010-filament-tpu95a.md) | TPU 95A HF, **1kg**, black (Bambu) | 1 | $42 | $42 | **Corrected from BOM v1.0 (was 0.5kg, doesn't exist)** |
| | | **Filament subtotal** | | | **$62** | |

## Hardware

| # | Catalog | Description | Qty | Unit | Subtotal | Notes |
|---|---|---|---|---|---|---|
| 18 | [cat-011](../../hardware-library/parts-catalog/cat-011-m3-shcs-kit.md) | M3 SHCS assortment kit | 1 | $15 | $15 | |
| 19 | [cat-012](../../hardware-library/parts-catalog/cat-012-m3-nyloc-nuts.md) | M3 nyloc nuts ×50 | 1 | $8 | $8 | |
| 20 | [cat-013](../../hardware-library/parts-catalog/cat-013-m3-heat-inserts.md) | M3 brass heat-set inserts ×100 | 1 | $12 | $12 | |
| 21 | (uncataloged, low-volume) | M2 SHCS assortment | 1 | $10 | $10 | |
| 22 | (uncataloged, low-volume) | Velcro battery straps ×3 | 1 pack | $10 | $10 | |
| 23 | (uncataloged, low-volume) | 3M VHB tape, 1/2" | 1 | $8 | $8 | |
| 24 | (uncataloged, low-volume) | Zip ties assortment | 1 | $8 | $8 | |
| 25 | (uncataloged, low-volume) | Heat shrink tubing kit | 1 | $10 | $10 | |
| | | **Hardware subtotal** | | | **$81** | |

---

## Cost breakdown

| Category | Cost |
|---|---|
| Airframe + electronics (incl. spare FC) | $499 |
| Power & charging | $212 |
| Radio (TX) | $80 |
| Ground station | $408 |
| Filament | $62 |
| Hardware | $81 |
| Tools (see `tooling.md`) | $311 |
| Solder consumables (cat-014, included in tooling) | — |
| **Total v1 build** | **~$1,653** |

### Per-airframe cost (v2+ when tools/radio/laptop already owned)

- Airframe + electronics minus spare FC: $374
- 4 batteries: ~$126 (some reusable from v1)
- Filament (per-print share): ~$10
- Hardware: ~$30
- **Per-additional-airframe: ~$400–540**

---

## Changes from v1.1 (2026-05-11)

1. **FC stack swap.** SpeedyBee F405 V4 BLS 55A → **Holybro Kakute H7 v1.5 + Tekko32 F4 4in1 50A ESC** ($94 → $125, +$31/unit, +$62 total with spare). V4 went OOS at GetFPV, Pyrodrone, and Amazon during procurement. Kakute H7 is ArduPilot-supported as target `KakuteH7`, ICM-42688P + H7 MCU (better than spec floor), 30.5×30.5mm (drop-in mounting), AM32 ESC firmware (DSHOT600 + bidi-DSHOT standard). GPS pad pinout note in "Outstanding flags" updated. Firmware README rewritten with branch-on-receipt flash procedure.
2. **Catalog edits driven by 2026-05-10 procurement re-research.** See `hardware-library/parts-catalog/` git history: cat-002 URL fix, cat-003 multi-variant page, cat-005 vendor swap to Holybro-direct, cat-006 Tower-variant URL pin, cat-007 price drop refresh, cat-008 spec bump to ≥100C with V2.0 130C as rank-1, cat-010 AMS-compatibility correction.

## Changes from v1.0

Driven by procurement research run on 2026-05-04:

1. **GPS swap.** Matek M10Q-5883 → Holybro M10 V2. Matek's M10 series is end-of-life. Holybro is in production, ArduPilot-supported, with bonus IP67 rating.
2. **TPU SKU corrected.** Bambu doesn't sell TPU 95A HF in 0.5kg. Updated to 1kg ($42 vs old $35) — gets us 2× the filament for 20% more.
3. **RX disambiguated.** Tower antenna variant chosen over Flat. Tower routes simply through canopy on outdoor builds; Flat is for racing layouts.
4. **Telem radio wattage specified.** 100mW chosen (BOM previously left this open). 500mW was the suggested middle option but offers no benefit at <500m range — costs more, runs hotter.
5. **Frame branding pinned.** TBS-branded Source One V5 at GetFPV chosen as canonical. RDQ and Pyrodrone variants stay as fallbacks (same open-source design).
6. **Battery vendor changed.** GetFPV instead of CNHL-direct. Higher unit cost (~$28 vs $21) but resolves US warehouse routing ambiguity and matches single-vendor consolidation policy.
7. **Prices refreshed.** Multiple lines saw +30–70% increase since BOM v1.0 (5 days ago). Reality is what's in the catalog now.
8. **Format change.** Each line now references a catalog entry by ID. Catalog holds the ranked SKU list, abstract spec, and reorder guidance. BOM is just "what to procure for this build."

## Outstanding flags

- Verify GetFPV stock at order time. Some core items were OOS as of 2026-05-04 — consider rank-2 SKUs in each catalog entry if still OOS.
- Toughbook CF-54 listings vary widely on eBay. Verify "daylight-readable" (sometimes called "outdoor display" or "sunlight-readable") in the listing photos before buying.
- Holybro M10 V2 cable connector may need clipping/resoldering to match Kakute H7 v1.5 GPS port (JST GH 6-pin). Plan for ~10 min of extra solder work.

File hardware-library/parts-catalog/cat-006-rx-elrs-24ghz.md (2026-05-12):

# RC Receiver — ELRS 2.4GHz

**Catalog ID:** cat-006
**Status:** active
**Last verified:** 2026-05-11

## Abstract spec

- ExpressLRS (ELRS) protocol, 2.4GHz band
- ELRS firmware version ≥3.x (current generation)
- CRSF output to FC (single UART, telemetry back to TX)
- Integrated SMD ceramic antenna (Tower or Flat form factor — both function equivalently; Tower has a 6mm vertical profile, Flat is flush at 3mm)
- 5V input (FC provides 5V on RX pad)
- ≤2g
- Pre-attached 4× silicon wires (5V, GND, RX, TX) for solder to FC pads
- Diversity: not required for v1 mission profile (<500m range); single-antenna is sufficient

## Ranked SKUs

| Rank | Mfr part | Vendor | URL | Unit price | Notes |
|---|---|---|---|---|---|
| 1 | BetaFPV ELRS Lite V1.2 2.4GHz Receiver w/ Flat Antenna | GetFPV | https://www.getfpv.com/betafpv-elrs-lite-v1-1-2-4ghz-receiver-w-flat-antenna.html | $8.99 | **promoted from Flat-variant fallback on 2026-05-11** — Tower variant was discontinued at BetaFPV. PCB 11×10×3mm, integrated SMD ceramic antenna (flush), pre-attached 4-wire cable, 0.46g. Ships with ELRS 3.3.0. |
| 2 | BetaFPV ELRS Lite V1.2 2.4GHz Receiver w/ Flat Antenna | BetaFPV direct | https://betafpv.com/products/elrs-lite-receiver | $8.99 | manufacturer-direct fallback |
| 3 | BetaFPV ELRS Lite 2.4GHz Receiver w/ Ceramic Tower antenna | BetaFPV direct | https://betafpv.com/products/elrs-lite-receiver | (discontinued) | sold out at BetaFPV as of 2026-05-11. Was rank-1 before the Flat substitution. PCB 10×10×6mm, integrated tower antenna, 0.47g. Listed for posterity. |
| 4 | RadioMaster RP1 ELRS RX | GetFPV | https://www.getfpv.com/ | ~$15 | matches RadioMaster Pocket TX brand; verify URL at order time |

## Reorder guidance

Suggested trigger: on hand ≤ 1. Suggested order qty: 1.

## Notes

- TX and RX must run **matching ELRS firmware versions**. Update both at the same time.
- Bind procedure: power TX in bind mode, power RX (3 quick power-cycles or hold bind button), they auto-pair.
- **Tower vs Flat antenna form factor:** both BetaFPV ELRS Lite variants use an integrated SMD ceramic antenna on the receiver PCB — no detachable pigtail in either. Tower is 6mm tall (vertical orientation), Flat V1.2 is 3mm tall (flush). For this build's antenna-mount design (`builds/v1/cad/antenna-mounts/`), both fit the same parametric cradle with a one-line `RX_H` change. The earlier "do not substitute" warning was based on incomplete info — removed.
- Always test RC link loss failsafe **on the bench** before any flight. Pull TX battery, verify RX outputs failsafe values to FC.

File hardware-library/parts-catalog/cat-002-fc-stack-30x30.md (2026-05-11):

# 30×30mm FC + 4-in-1 ESC Stack (ArduPilot-supported)

**Catalog ID:** cat-002
**Status:** active
**Last verified:** 2026-05-11

## Abstract spec

- 30.5×30.5mm mounting (4mm hole pattern)
- F4 (STM32F405) MCU minimum; F7 or H7 acceptable
- Listed in ArduPilot's [supported autopilots](https://ardupilot.org/copter/docs/common-autopilots.html). Non-negotiable.
- ICM-42688P or equivalent gyro
- Onboard barometer (BMP280 or better)
- 4-in-1 ESC bundled, ≥45A continuous, BLHeli_S or BLHeli_32 / AM32, DSHOT600 minimum
- Bidirectional DSHOT preferred (RPM filtering)
- USB-C connector
- Onboard current sensor (for ArduPilot battery failsafes)
- Dual BEC (5V + 9V) preferred for peripheral powering

## Ranked SKUs

| Rank | Mfr part | Vendor | URL | Unit price | Notes |
|---|---|---|---|---|---|
| 1 | Kakute H7 v1.5 + Tekko32 F4 4in1 50A ESC Stack | Holybro direct | https://holybro.com/products/kakute-h7-v1-stacks | $124.99 | **promoted from rank-3 on 2026-05-11** after SpeedyBee F405 V4 went OOS across all distributors. Variant selector at checkout: pick "Kakute H7 v1.5 / Tekko32 F4 4in1 50A ESC". 65A "Metal" variant exists at $149.99 — overkill for v1's 5"/4S build. |
| 2 | SpeedyBee F405 V4 BLS 55A 30x30 Stack | GetFPV | https://www.getfpv.com/speedybee-f405-v4-stack-f4-v4-fc-55a-blheli-s-esc-30x30.html | $93.99 | cheaper but OOS at GetFPV and Pyrodrone as of 2026-05-11. Earlier rank-1; demoted when stock disappeared. |
| 3 | SpeedyBee F405 V3 BLS 50A 30x30 Stack | GetFPV / Pyrodrone | (verify at order time) | ~$80–90 | older revision, same form factor and ArduPilot family. Use if V4 stays OOS and Kakute is also unavailable. |

## Reorder guidance

Suggested trigger: on hand ≤ 1. Suggested order qty: 1.

## Notes

- ArduCopter target name depends on the SKU. Verify the target before flashing:
  - Kakute H7 v1.5 (rank-1): `KakuteH7` — `https://firmware.ardupilot.org/Copter/stable/KakuteH7/`
  - SpeedyBee F405 V4 (rank-2): `SpeedyBeeF4V4` — `https://firmware.ardupilot.org/Copter/stable/SpeedyBeeF4V4/`
  - SpeedyBee F405 V3 (rank-3): `SpeedyBeeF4V3`
- First-flash procedure differs by vendor. SpeedyBee stacks ship with Betaflight and need DFU + STM32CubeProgrammer for the first ArduCopter flash. Holybro Kakute stacks typically ship with a bootloader pre-installed; verify what firmware (if any) is on the board on receipt before deciding the flash path. See `builds/v1/firmware/README.md`.
- Tekko32 4in1 ESCs ship with AM32 firmware (modern open-source successor to BLHeli_32). Supports DSHOT600 and bidirectional DSHOT out of the box.
- Spare stack recommended for first-builders (cooked pads happen). v1 BOM includes one.
- 6S-capable (Kakute H7) but we run 4S in v1. Don't mismatch motor KV with battery S-count.

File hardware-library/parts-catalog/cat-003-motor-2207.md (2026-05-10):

# Brushless Motor — 2207, 1750–2000KV (4S)

**Catalog ID:** cat-003
**Status:** active
**Last verified:** 2026-05-10

## Abstract spec

- 2207 stator (22mm diameter, 7mm height)
- 1750–2000KV (matched to 4S battery, 5" prop)
- M5 prop shaft thread (standard for 22xx motors)
- 16×16mm and 19×19mm motor mount hole patterns (Source One V5 arms use 16×16 with M3)
- N52 magnets minimum
- Continuous current rating ≥30A on 4S
- Pre-soldered motor leads (~150mm)

## Ranked SKUs

| Rank | Mfr part | Vendor | URL | Unit price | Notes |
|---|---|---|---|---|---|
| 1 | EMAX ECO II 2207 (1700/1900/2400KV multi-variant listing) | GetFPV | https://www.getfpv.com/emax-eco-ii-series-2207-motor-1700kv-1900kv-2400kv.html | $20.99 | **multi-variant page — select 1900KV at checkout** |
| 2 | EMAX ECO II 2207 1900KV | RDQ | https://www.racedayquads.com/ | ~$20 | OOS at last check 2026-05-04; reverify before ordering |
| 3 | T-Motor F40 Pro V 2306.5 1950KV | GetFPV | https://www.getfpv.com/ | ~$26 | premium alternative; verify URL at order time |

## Reorder guidance

Keep one full set (4) on hand for crash recovery. Order in sets of 4.

Suggested trigger: on hand ≤ 4. Suggested order qty: 4.

## Notes

- **Variant discipline at order time:** rank-1 GetFPV listing covers 1700/1900/2400KV from a single product page. The 1900KV variant is the only one matched to our 4S+5"+2207 spec. Always reconfirm the variant selector on the page before checkout.
- Always order spares with new builds. Crashes destroy motors silently (bent shafts, demagnetized stators).
- **Motor direction is set in firmware**, not by motor SKU. CW/CCW labels on motors refer to which way the bell spins, but in BLHeli configurator we flip direction as needed. Don't worry about CW/CCW pairs at order time.
- Motors run hotter than 70°C at hover = something is wrong (prop binding, ESC mistuned, motor mount not flat). Investigate before flying again.

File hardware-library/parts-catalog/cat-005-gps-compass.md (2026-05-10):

# GNSS + Compass Module (mast-mountable)

**Catalog ID:** cat-005
**Status:** active
**Last verified:** 2026-05-10

## Abstract spec

- u-blox M9N or M10 GNSS chip (M10 preferred for v3+ vision-augmented autonomy)
- Multi-constellation: GPS + GLONASS + Galileo + BeiDou
- Onboard magnetometer (IST8310, QMC5883L, or RM3100 acceptable)
- ≥25×25mm patch antenna
- Rechargeable backup battery (warm-start support)
- ArduPilot-supported (PX4 1.14+, ArduPilot 4.3+, INAV 5.0+)
- UBlox UBX protocol over UART, I²C for compass
- Compatible with mast-mounting (≥80mm above FC required for clean signal + low mag interference)
- Sub-15g preferred for 5" airframe

## Ranked SKUs

| Rank | Mfr part | Vendor | URL | Unit price | Notes |
|---|---|---|---|---|---|
| 1 | Holybro M10 GPS V2 (IP67, 10-pin JST GHR) | Holybro direct | https://holybro.com/products/m10-gps | ~$45 | **GetFPV does not carry the V2** — manufacturer-direct is the only V2 source as of 2026-05-10 |
| 2 | Holybro M10 GPS Standard (no IP67) | GetFPV | https://www.getfpv.com/ | $61.49 | older SKU, lacks IP67; functionally fine for v1 dry-only ops. OOS at GetFPV 2026-05-10. Verify exact URL at order time. |
| 3 | Holybro M9N GPS | GetFPV | https://www.getfpv.com/ | ~$40 | older chip, identical interface; verify URL at order time |

## Reorder guidance

Suggested trigger: on hand ≤ 1. Suggested order qty: 1.

## Notes

- **Replaced Matek M10Q-5883 (EOL as of 2026 per Matek).** Holybro M10 V2 is the current-production equivalent with bonus IP67 rating.
- **Vendor concentration risk noted.** Rank-1 (Holybro-direct) is single-source for the V2 SKU. The M10 Standard at GetFPV is a viable fallback for v1 since v1 is dry-only and IP67 is not in our abstract spec — but it's a different SKU, not a parallel vendor. If both sources go OOS, the rank-3 M9N is the last fallback. Revisit if the V2 stays single-vendor through v2.
- Cable connector: confirm pinout matches SpeedyBee F405 V4 GPS pads. Holybro ships with bare-end or JST GHR depending on SKU; expect to clip and resolder for our FC.
- Compass orientation: ArduPilot may require `COMPASS_ORIENT=6 (Yaw270)` per Holybro docs.
- Mast height ≥80mm. **Non-negotiable for clean fix and low mag interference.**
- v3 may upgrade to RTK-capable module (Holybro H-RTK F9P) for cm-precision positioning.

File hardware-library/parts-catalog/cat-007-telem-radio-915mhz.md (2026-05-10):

# Telemetry Radio Pair — 915MHz SiK

**Catalog ID:** cat-007
**Status:** active
**Last verified:** 2026-05-10

## Abstract spec

- 915MHz band (US-legal). EU/UK builds use 433MHz instead.
- 100mW RF output (range ~1km, sufficient for v1 mission at <500m)
- SiK firmware (Silicon Labs Si1000-based or compatible STM32 reimplementation)
- USB end for ground station connection (Mission Planner / QGC)
- TTL UART end for FC connection (3.3V or 5V tolerant)
- MAVLink 2 protocol
- Sold as matched pair (pre-bound)
- ≤8g per radio

## Ranked SKUs

| Rank | Mfr part | Vendor | URL | Unit price (pair) | Notes |
|---|---|---|---|---|---|
| 1 | Holybro SiK Telemetry Radio V3 915MHz 100mW (pair) | GetFPV | https://www.getfpv.com/ | ~$39 | OOS at GetFPV 2026-05-10. Verify exact URL at order time. Price dropped ~35% from prior catalog ($60 → $39). |
| 2 | Holybro SiK Telemetry Radio V3 915MHz 100mW (pair) | Holybro direct | https://holybro.com/ | ~$59 | manufacturer-direct |
| 3 | RFD900x (US 915MHz) | mfr-direct | https://store.rfdesign.com.au/ | ~$200/pair | overkill for v1 — consider for v3+ long-range |

## Reorder guidance

Sold as a pair (one air radio + one ground radio). Reorder one full pair when pair is destroyed or lost.

Suggested trigger: on hand ≤ 0. Suggested order qty: 1.

## Notes

- **100mW is the right pick for v1.** 500mW costs more and runs hotter without range benefit at <500m. 1W is single-radio (you'd need to buy two), different product.
- Air radio mounts on the airframe; ground radio plugs into the Toughbook USB port.
- Antenna should be vertical and clear of carbon fiber for best link.
- For v3+ swarm work this won't be the comm link — swarm needs a mesh-capable radio. SiK is point-to-point only.

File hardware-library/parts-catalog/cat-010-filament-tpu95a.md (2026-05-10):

# Filament — TPU 95A, Black

**Catalog ID:** cat-010
**Status:** active
**Last verified:** 2026-05-10

## Abstract spec

- TPU 95A shore hardness (95A is the standard "soft but printable" range)
- 1.75mm filament diameter
- 1kg spool
- Print temp 220–235°C nozzle, 50–60°C bed
- Black
- **Manual feed only — Bambu TPU 95A HF is NOT AMS-compatible per Bambu's product page.** AMS Series compatibility was incorrectly claimed in the prior catalog revision; this has been corrected against the manufacturer's own copy.

## Ranked SKUs

| Rank | Mfr part | Vendor | URL | Unit price | Notes |
|---|---|---|---|---|---|
| 1 | Bambu TPU 95A HF, 1kg, Black | Bambu Lab | https://us.store.bambulab.com/ | ~$42 | RFID-tagged. **NOT AMS-compatible** — manual feed required (per Bambu product page). |
| 2 | Polymaker PolyFlex TPU95, 1kg, Black | Amazon | Amazon search | ~$35 | not AMS-compatible |
| 3 | Sunlu TPU 95A, 1kg, Black | Amazon | Amazon search | ~$25 | budget option, not AMS-compatible |

## Reorder guidance

~50g per drone of TPU for soft mounts and antenna tubes. 1kg = ~20 drones of TPU parts. Reorder when down to last spool.

Suggested trigger: on hand ≤ 1. Suggested order qty: 1.

## Notes

- **Note SKU corrected from BOM v1.0:** Bambu sells TPU 95A HF only in 1kg (not 0.5kg as previously listed).
- **AMS compatibility correction (2026-05-10):** the prior catalog stated Bambu TPU 95A HF was AMS-compatible. Bambu's current product page explicitly states "All AMS Series NOT Compatible." Plan for manual external-spool feeding. The P2S external spool holder is on the side of the printer; verify the path keeps the TPU dry-box-routed if possible.
- Print slow (≤30 mm/s). TPU stringing at high speed is unfixable.
- Minimize retraction — TPU is elastic and retraction creates stringing on small features.
- Store in dry box. Wet TPU prints with bubbles and weakens significantly.

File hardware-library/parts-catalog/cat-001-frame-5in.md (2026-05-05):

# 5-inch Quadcopter Frame (Source One V5)

**Catalog ID:** cat-001
**Status:** active
**Last verified:** 2026-05-05

## Abstract spec

- 5-inch prop class (≤220mm motor-to-motor diagonal, X-config)
- Open-source design (multiple manufacturers must produce it)
- 30.5×30.5mm FC stack mounting holes (with 20×20mm fallback pattern is fine but not required)
- ≥3mm 3K twill carbon fiber arms
- Replaceable arms (single-arm replacement <$10)
- M3 standard fasteners throughout
- Compatible with 1404–2207 motor mount patterns

## Ranked SKUs

| Rank | Mfr part | Vendor | URL | Unit price | Notes |
|---|---|---|---|---|---|
| 1 | TBS Source One V5 5" Frame Kit | GetFPV | https://www.getfpv.com/tbs-source-one-v5-5-frame-kit.html | ~$39 | OOS as of 2026-05-04 — verify before order |
| 2 | RDQ Source One V5 5" Freestyle Frame Kit | RDQ | https://www.racedayquads.com/ | ~$42 | OOS as of 2026-05-04 |
| 3 | Pyrodrone Source One V5 5" | Pyrodrone | https://pyrodrone.com/ | varies | last fallback |

All three are the same open-source design with cosmetic branding differences. Arm patterns and screw holes are interchangeable.

## Reorder guidance

Suggested trigger: on hand ≤ 1. Suggested order qty: 1.

## Notes

- Spare arms are essential — Source One V5 arms break in moderate crashes. Carry spares.
- Top plate not strictly required for v1 (we 3D-print our own canopy). Some kits ship without one.
- After two builds, evaluate whether to switch to a stiffer/more expensive frame (ImpulseRC Apex) or move to printed PA-CF structural plate (graduates to v2 design).

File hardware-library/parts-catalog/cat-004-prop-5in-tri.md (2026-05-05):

# Propeller — 5×4.3×3 Tri-blade

**Catalog ID:** cat-004
**Status:** active
**Last verified:** 2026-05-05

## Abstract spec

- 5-inch diameter (≤5.1")
- Tri-blade (3 blades)
- 4.3" pitch (acceptable range: 4.0–4.5")
- M5 shaft bore (standard for 22xx motors)
- Polycarbonate or glass-fiber-reinforced nylon
- Sold in sets of 4 (2 CW + 2 CCW)
- Compatible with prop nut (rubber prop wrench fits)

## Ranked SKUs

| Rank | Mfr part | Vendor | URL | Unit price (set of 4) | Notes |
|---|---|---|---|---|---|
| 1 | HQ Prop V2S Freestyle 5x4.3x3 | GetFPV | https://www.getfpv.com/ | ~$4 | verify SKU |
| 2 | HQ Prop V2S Freestyle 5x4.3x3 | RDQ | https://www.racedayquads.com/products/hq-prop-v2s-freestyle-5x4-3x3-tri-blade-5-prop-4-pack | ~$4 | in stock at last check |
| 3 | Gemfan Hurricane 51466 | GetFPV | https://www.getfpv.com/ | ~$4 | alternative if HQ OOS |

## Reorder guidance

Props are the most-broken part on the drone. Keep at least 2 sets on hand (8 props = 1 set per motor × 2 spares). Reorder 4 sets at a time.

Suggested trigger: on hand ≤ 8. Suggested order qty: 16.

## Notes

- Inspect props before every flight. **Any nick, crack, or chip = retire the prop.** Imbalanced props cause motor heat and bad IMU data.
- Cheap; don't be precious. Retire on first sign of damage.
- Buy in bulk. v1 field kit lists 8 spare props as standard.
- Quantity is tracked per **prop**, not per set.

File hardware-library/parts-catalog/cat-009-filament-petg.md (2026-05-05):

# Filament — PETG, Black

**Catalog ID:** cat-009
**Status:** active
**Last verified:** 2026-05-05

## Abstract spec

- PETG (polyethylene terephthalate glycol)
- 1.75mm filament diameter
- 1kg spool
- Print temp 230–250°C nozzle, 70–80°C bed
- Black (UV resistance + visual contrast for assembly photos)
- Compatible with Bambu AMS (smooth spool, RFID tag preferred but not required)
- Dimensional accuracy ≤±0.05mm

## Ranked SKUs

| Rank | Mfr part | Vendor | URL | Unit price | Notes |
|---|---|---|---|---|---|
| 1 | Bambu PETG Basic, 1kg, Black | Bambu Lab | https://us.store.bambulab.com/ | ~$13–20 | RFID-tagged for AMS, frequent sales |
| 2 | Polymaker PolyLite PETG, 1kg, Black | Amazon | Amazon search | ~$25 | non-RFID alternative |
| 3 | Overture PETG, 1kg, Black | Amazon | Amazon search | ~$22 | non-RFID alternative |

## Reorder guidance

~150–200g per drone of PETG used for canopies, masts, battery trays. 1kg = ~5 drones of PETG parts.

Suggested trigger: on hand ≤ 1. Suggested order qty: 1.

## Notes

- Quantity is in **spools**, not grams. Track partial spools as fractional usage in build notes if needed.
- Bambu's RFID tags auto-configure print settings on the P2S — saves slicer fiddling. Worth the slight premium.
- Dry filament before printing if it's been open >2 weeks. Wet PETG = stringy prints + weak layer adhesion.
- PETG creep onset ~75°C — fine for canopies but **not for parts touching motor mounts** (motor housings hit ~60°C at hover with 5°C margin only).

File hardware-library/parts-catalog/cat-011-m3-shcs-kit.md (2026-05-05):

# M3 SHCS Hardware Kit (Frame Fasteners)

**Catalog ID:** cat-011
**Status:** active
**Last verified:** 2026-05-05

## Abstract spec

- M3 socket-head cap screws (SHCS)
- Lengths: 6mm, 8mm, 10mm, 12mm, 16mm, 20mm minimum coverage
- Stainless steel (A2 or 18-8) or alloy 12.9
- Hex drive (2.5mm bit)
- Quantity ≥30 of each length

## Ranked SKUs

| Rank | Mfr part | Vendor | URL | Unit price | Notes |
|---|---|---|---|---|---|
| 1 | M3 SHCS assortment kit, stainless | Amazon | Amazon search "M3 SHCS assortment kit stainless" | ~$15 | non-flight item, Amazon OK |
| 2 | Iflight M3 hardware kit | GetFPV | https://www.getfpv.com/ | ~$10 | drone-specific lengths |

## Reorder guidance

An assortment kit lasts many builds. Reorder when low across multiple lengths.

Suggested trigger: on hand ≤ 1. Suggested order qty: 1.

## Notes

- Quantity tracked in **kits**, not individual screws. Don't try to count every M3 screw.
- Apply Loctite 243 (blue) to motor screws and any vibration-loaded threads.
- **Don't mix** stainless and alloy in the same airframe — galvanic corrosion isn't an issue but inconsistent thread feel can mask problems.

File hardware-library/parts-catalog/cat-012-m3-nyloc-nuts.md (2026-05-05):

# M3 Nylon-Insert Lock Nuts (Nyloc)

**Catalog ID:** cat-012
**Status:** active
**Last verified:** 2026-05-05

## Abstract spec

- M3 thread, 0.5mm pitch
- Nylon insert (one-time-use, not reusable after a few cycles)
- Stainless steel or zinc-plated steel
- Standard hex flat (5.5mm wrench)
- DIN 985 / ISO 10511 standard

## Ranked SKUs

| Rank | Mfr part | Vendor | URL | Unit price (qty 50) | Notes |
|---|---|---|---|---|---|
| 1 | M3 nylon-insert lock nuts ×50 | Amazon | Amazon search | ~$8 | non-flight item, Amazon OK |
| 2 | M3 nyloc nuts | McMaster-Carr | https://www.mcmaster.com/ | varies | for orderly bulk procurement |

## Reorder guidance

Suggested trigger: on hand ≤ 20. Suggested order qty: 50.

## Notes

- Used at motor mounts (motor screw passes through arm, threads into nyloc on bottom side).
- Replace nyloc nuts after **2 reuse cycles maximum.** Nylon insert wears.
- If you find a stripped nyloc, retire it — don't try to "tighten harder."

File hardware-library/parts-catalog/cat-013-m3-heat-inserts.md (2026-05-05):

# M3 Heat-Set Threaded Inserts (Brass)

**Catalog ID:** cat-013
**Status:** active
**Last verified:** 2026-05-05

## Abstract spec

- M3-0.5 thread
- Brass (knurled outer surface for thermal embedding)
- Length: 5mm or 6mm
- OD: 4.0–4.5mm (matches printed boss with 4.2mm hole)
- For embedding in 3D-printed parts via soldering iron

## Ranked SKUs

| Rank | Mfr part | Vendor | URL | Unit price (qty 100) | Notes |
|---|---|---|---|---|---|
| 1 | M3 brass heat-set inserts ×100 | Amazon | Amazon search "M3 heat set inserts" | ~$12 | non-flight, Amazon fine |
| 2 | M3 heat-set threaded inserts (Ruthex brand) | Amazon | Amazon search | ~$18 | premium brand, very consistent |

## Reorder guidance

Suggested trigger: on hand ≤ 20. Suggested order qty: 100.

## Notes

- Install with soldering iron at 240°C, dedicated insert-installation tip preferred (or use a smooth conical tip you don't mind getting brass on).
- Press in slowly; let the iron's heat pull the insert in. Forcing it cracks the print.
- Insert should sit 0.1–0.2mm proud of the surface, then is squashed flush by the mating screw — this gives best pull-out strength.
- Design printed parts with 4.2mm holes and short lead-in chamfers (0.5mm × 45°).

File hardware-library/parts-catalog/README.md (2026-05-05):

# Parts Catalog

The parts catalog is the canonical source of truth for **what parts are acceptable** for builds in this project. It defines abstract specifications, ranks SKUs that meet each spec, and captures reorder rationale.

## Catalog entry format

One file per entry: `cat-NNN-short-description.md`. Every entry follows this structure:

```markdown
# [Part name]

**Catalog ID:** cat-NNN
**Status:** active | retired | deferred
**Last verified:** YYYY-MM-DD

## Abstract spec
- requirement 1
- requirement 2
- ...

## Ranked SKUs

| Rank | Mfr part | Vendor | URL | Unit price | Notes |
|---|---|---|---|---|---|
| 1 | ... | GetFPV | ... | $X | preferred |
| 2 | ... | RDQ | ... | $X | fallback |

## Reorder guidance
[rationale paragraph + suggested trigger / order quantity]

## Notes
[design notes, gotchas, replacement strategy]
```

## Field semantics

**Abstract spec** — the requirements that distinguish "this catalog entry" from a different one. If a candidate SKU doesn't meet the spec, it shouldn't be in the ranked list — open a new catalog entry instead. Specs change rarely; SKU rankings change often.

**Ranked SKUs** — preference order. Procurement workflows try rank 1 first, fall back through the list. Prices are last-verified snapshots (re-checked at order time). URLs link to the product page on the vendor's site when known.

**Reorder guidance** — advisory text for procurement workflows. May suggest a trigger threshold and order quantity, but these are recommendations, not enforced state.

## Status field

- `active` — currently used in shipping builds
- `deferred` — spec'd but not yet used (e.g., parts only needed for v3+)
- `retired` — superseded by another entry; kept for historical reference

## When to add a new entry

When a new requirement emerges that no existing entry satisfies. **Don't fork an entry just because a SKU is OOS** — add the alternative as a lower-ranked SKU in the existing entry.

When you legitimately need a new entry (e.g., a 7" frame for a different build), copy the template above and increment the `cat-NNN` ID.

## When to update an entry

- A new SKU emerges that meets the spec → add it to the ranked list at the appropriate rank.
- A SKU goes EOL → strike it from the list with a strikethrough or remove and note in the catalog entry's commit message.
- Vendor URL changes → update.
- Prices drift significantly (>20%) → update with a fresh `Last verified` date.
- The abstract spec needs to change → consider whether this is the same part with a tightened/loosened spec, or a new part that warrants a new entry.

## Vendor preference

Single-vendor consolidation, GetFPV preferred. Fallback order: RDQ → manufacturer-direct → Amazon (non-flight items only). Revisit if GetFPV stops carrying core SKUs or has persistent stock problems.

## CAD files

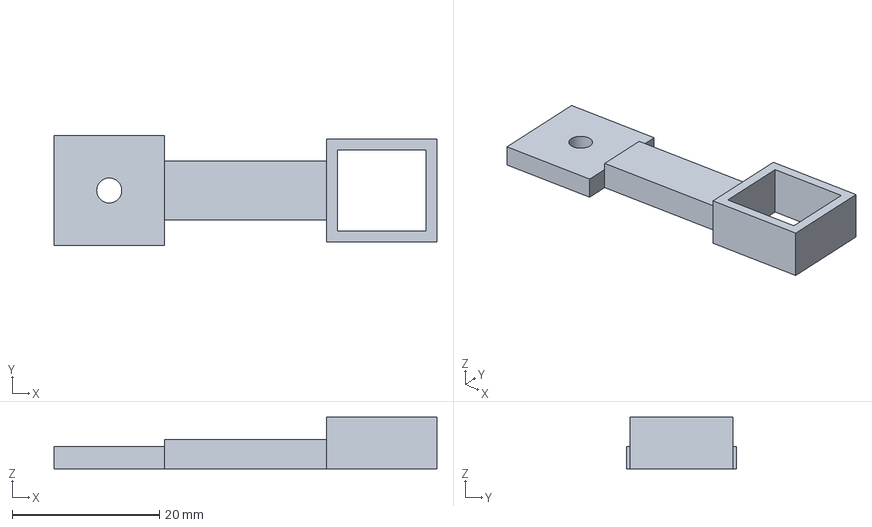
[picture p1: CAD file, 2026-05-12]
builds/v1/cad/antenna-mounts/antenna-mount-v1.step
52.0 x 15.0 x 7.00 mm

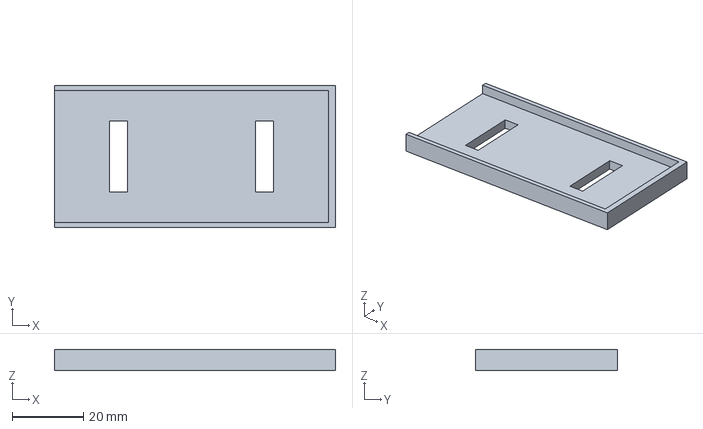
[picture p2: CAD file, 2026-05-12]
builds/v1/cad/battery-tray/battery-tray-v1.step
79.0 x 40.0 x 6.00 mm

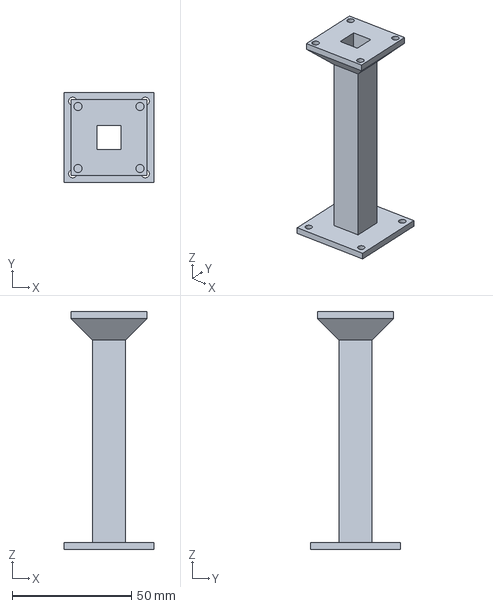
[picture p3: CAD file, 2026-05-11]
builds/v1/cad/gps-mast/gps-mast-v1.step
38.0 x 38.0 x 100.0 mm

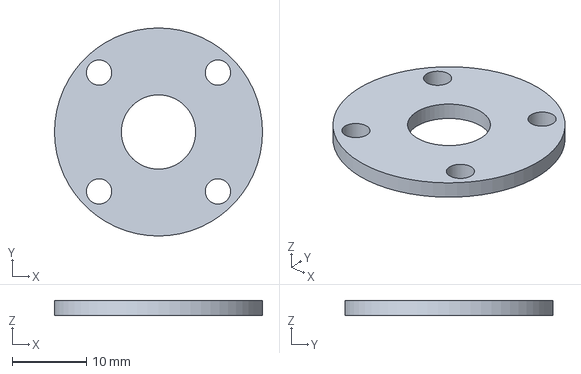
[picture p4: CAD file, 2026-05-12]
builds/v1/cad/motor-soft-mounts/motor-soft-mount-v1.step
28.0 x 28.0 x 2.00 mm

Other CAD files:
builds/v1/cad/antenna-mounts/antenna-mount-v1.stl
builds/v1/cad/battery-tray/battery-tray-v1.stl
builds/v1/cad/gps-mast/gps-mast-v1.stl
builds/v1/cad/motor-soft-mounts/motor-soft-mount-v1.stl

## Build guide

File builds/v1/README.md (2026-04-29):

# Build v1 — Learning Vehicle

**Status:** 🟡 In design — parts ordering pending
**Goal:** Fly a 4-waypoint autonomous mission within 7 days of parts arrival
**Mission spec:** 18m × 18m square at 5m AGL, 2 m/s cruise, AUTO takeoff and land

## Quick links

- [Requirements](./requirements.md) — locked v0.3
- [BOM](./bom.md) — parts and SKUs to order
- [Tooling](./tooling.md) — tools to order
- [Assembly notes](./assembly/notes.md) — populated as we build
- [Firmware](./firmware/) — ArduCopter parameters and flashed binaries
- [Flight logs](./flight-logs/) — per-flight artifacts

## Test plan summary

| Gate | Status | Date |
|---|---|---|
| G1: Bench power-on | ⚪ | — |
| G2: RX bind + arming | ⚪ | — |
| G3: Motor direction + ESC cal | ⚪ | — |
| G4: IMU + compass cal | ⚪ | — |
| G5: GPS lock | ⚪ | — |
| G6: Tethered hover | ⚪ | — |
| G7: Free hover (STABILIZE) | ⚪ | — |
| G8: GPS position hold (LOITER) | ⚪ | — |
| G9: RTH test | ⚪ | — |
| G10: AUTO mission | ⚪ | — |

Update this table as gates pass. ⚪ = not yet, 🟡 = in progress, ✅ = passed, ❌ = failed.

## Week-1 schedule (estimate, parts-arrival-relative)

| Day | Activity |
|---|---|
| Day 0 | Order all parts (BOM + tooling). FAA registration + TRUST cert. Identify flight site. |
| Day 1–3 | Parts ship. Set up Mission Planner on Toughbook. Watch soldering primers. Print accessory parts. |
| Day 4 (parts arrive) | Solder motors to ESC, install RX, install GPS+compass. G1, G2 on bench. |
| Day 5 | G3 (motor direction), G4 (compass cal), G5 (GPS lock). Configure ArduCopter params. |
| Day 6 | G6 (tethered hover) → G7 (free STABILIZE) → G8 (LOITER). Field site. |
| Day 7 | G9 (RTH) → G10 (AUTO mission). 🎯 Target met. |

## Open work for owner

- [ ] FAA recreational registration ($5)
- [ ] TRUST certificate (free)
- [ ] Verify flight area is Class G airspace via B4UFLY
- [ ] Order parts per BOM
- [ ] Order tools per tooling.md
- [ ] Set up GitHub repo

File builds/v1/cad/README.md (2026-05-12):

# v1 — CAD

Printed parts for the v1 airframe.

## Parts list

| Folder | Part | Filament | Status |
|---|---|---|---|
| `canopy/` | Top canopy + GPS/RX mount | PETG | ⚪ Not designed |
| `gps-mast/` | GPS mast (≥80mm tall, RF-transparent) | PETG | 🟡 v1 designed, awaiting print + fit-check |
| `antenna-mounts/` | ELRS receiver mount for BetaFPV ELRS Lite V1.2 Flat (×1) | TPU 95A | 🟡 v1 designed, awaiting print + fit-check |
| `battery-tray/` | Battery tray + Velcro strap loop | PETG | 🟡 v1 designed, awaiting print + fit-check |
| `motor-soft-mounts/` | Vibration-isolating motor mounts (×4) | TPU 95A | 🟡 v1 designed, awaiting print + fit-check |
| `standoffs/` | M3 frame standoffs (optional, can buy aluminum) | TPU 95A | ⚪ Not designed |

## Folder structure (per part)

Following `docs/repo-conventions.md`:

```
<part-name>/
├── README.md                              # design intent, mounting, fit notes
├── <part-name>-v1.py                      # source of truth (CadQuery / Python)
├── <part-name>-v1.step                    # exported from .py — kept in git for non-Python reviewers
├── <part-name>-v1.stl                     # exported from .py — direct slice in Bambu Studio
├── <part-name>-v1.3mf                     # slicer-ready, profile baked in (from Bambu Studio)
├── <part-name>-v1.slicer-profile.json     # exported Bambu Studio profile
└── notes.md                               # print orientation, supports, lessons
```

Increment the version (`v2`, `v3`) for any geometry change. Old versions stay — we keep history.

## CAD tool

[CadQuery](https://cadquery.readthedocs.io/) (parametric Python). `.py` files are source of truth, STEP and STL are exported artifacts. See `tools/cad/README.md` for env setup.

Why: plain-text, diff-friendly, branch-mergeable, AI-editable. STEP export is reusable in Fusion 360 / OnShape / FreeCAD if a part graduates later.

## Print parameters (Bambu P2S, 0.4mm stock nozzle)

### PETG defaults
- Nozzle: 240°C
- Bed: 70°C
- Layer: 0.2mm
- Walls: 4
- Infill: 30% gyroid
- Top/bottom layers: 5

### TPU 95A defaults
- Nozzle: 230°C
- Bed: 50°C
- Layer: 0.2mm
- Walls: 3
- Infill: 25% gyroid
- Print speed: ≤30 mm/s (TPU is slow, don't fight it)
- Retraction: minimize (stringy filament)

These are starting points. Tune per part; commit the tuned profile to the part's folder.

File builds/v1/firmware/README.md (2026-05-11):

# v1 — Firmware

ArduCopter firmware and parameters for build v1.

## Folder layout

```
firmware/
├── README.md (this file)
├── flashed/                    # The exact .apj we put on the airframe
│   └── (e.g. arducopter-4.5.7-KakuteH7.apj)
└── params/
    ├── v1-001.params           # Per-airframe parameter dump (committed before each flight)
    └── v1-default.params       # Tuned baseline for the v1 design
```

## Initial flash workflow (first time on a new FC)

The v1 build uses the **Holybro Kakute H7 v1.5 + Tekko32 F4 50A ESC** stack (ArduCopter target `KakuteH7`). Flash path depends on what firmware (if any) is on the board when it arrives — verify on receipt before choosing a path below.

### Step 0 — verify what's on the board

Plug USB into the FC and connect to Mission Planner (or Betaflight Configurator). One of three states:

- **Already on ArduCopter** → skip to step 4 (update to latest stable).
- **ArduCopter bootloader only** (board appears as "ArduPilot Bootloader" in MP) → skip to step 4.
- **Betaflight or unknown** → start at step 1 (DFU + STM32CubeProgrammer).

### DFU first-flash path (Betaflight or blank board)

1. Download the latest stable ArduCopter firmware from https://firmware.ardupilot.org/Copter/stable/KakuteH7/
2. You want **`arducopter_with_bl.hex`** for the first flash (includes bootloader).
3. Save to `flashed/`.
4. Hold the BOOT button on the FC and plug USB into the laptop. FC enters DFU mode.
5. Use STM32CubeProgrammer (free from ST) to flash the .hex.
6. Disconnect USB, plug back in WITHOUT BOOT pressed. ArduCopter is now running.
7. From here on, use Mission Planner's "Install Firmware" → "Load custom firmware" to load `.apj` files.

### Mission Planner update path (board already has ArduPilot bootloader)

1. Download `arducopter.apj` (NOT `_with_bl.hex`) from https://firmware.ardupilot.org/Copter/stable/KakuteH7/
2. Save to `flashed/`.
3. In Mission Planner: Setup → Install Firmware → Load custom firmware → select the `.apj`.
4. FC reboots running ArduCopter.

### If you switch FC SKUs

The target name in URLs and filenames changes. Lookup table (matches `cat-002` ranked SKUs):

| FC SKU | ArduCopter target |
|---|---|
| Holybro Kakute H7 v1.5 (current v1 build) | `KakuteH7` |
| SpeedyBee F405 V4 | `SpeedyBeeF4V4` |
| SpeedyBee F405 V3 | `SpeedyBeeF4V3` |

## Param management

- `v1-default.params` is the canonical starting config for the v1 airframe design.
- Each physical airframe gets its own params file: `v1-001.params`, `v1-002.params`, etc.
- **Before every flight session:** dump current params from MP (Config → Full Parameter List → Save to file) and commit.
- **After tuning:** update `v1-default.params` if the changes apply to the design generally; otherwise leave it in the per-airframe file.

## Mission upload

Missions are not stored in the firmware repo (they're per-mission, ephemeral). Save `.waypoints` files alongside flight logs in `../flight-logs/<flight-id>/mission.waypoints`.

## Failsafe params (must be set before first flight)

Configured in `v1-default.params`:

| Parameter | Value | Purpose |
|---|---|---|
| `FS_THR_ENABLE` | 1 (RTL) | RC link loss → RTH |
| `BATT_FS_LOW_ACT` | 2 (RTL) | Low battery → RTH at 30% |
| `BATT_LOW_VOLT` | 14.4 (4S) | 30% threshold |
| `BATT_FS_CRT_ACT` | 1 (Land) | Critical battery → land at current pos |
| `BATT_CRT_VOLT` | 13.6 (4S) | 20% threshold |
| `FENCE_ENABLE` | 1 | Geofence active |
| `FENCE_TYPE` | 7 (alt + circle + polygon) | |
| `FENCE_RADIUS` | 30 (m) | Tight for v1 mission |
| `FENCE_ALT_MAX` | 15 (m) | Tight for v1 mission |
| `FENCE_ACTION` | 1 (RTL) | |
| `EK3_SRC1_YAW` | 1 (Compass) | |

Full param file will be generated and committed before G6.

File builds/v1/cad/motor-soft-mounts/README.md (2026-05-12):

# Motor soft-mount

TPU 95A vibration-damping pad between each motor and the carbon arm. The M3 mount screws compress the pad slightly when torqued, and the TPU's residual compliance absorbs high-frequency motor vibration before it reaches the FC's gyro.

## Quantity: 4

One per motor.

## Geometry summary

| Dimension | Value | Notes |
|---|---|---|
| Outer diameter | 28 mm | matches EMAX ECO II 2207 motor base |
| Thickness | 2 mm | nominal compression range |
| Mount holes | 4 × M3 clearance (3.4 mm), 16 × 16 mm pattern | Source One V5 / EMAX 2207 standard |
| Center bore | 10 mm | clearance for motor base bearing boss |
| Volume per part | ~1.0 cm³ | ≈ 0.3 g per pad in TPU 95A at 25% infill |

## Mounting interface

**Stack-up (bottom → top):**

1. M3 SHCS head (from below the arm)
2. Source One V5 carbon arm
3. **This pad (TPU)**
4. EMAX ECO II 2207 motor base
5. M3 thread engaged in motor

Screws torque normally; the TPU pad compresses slightly under tightening pressure. Don't crush it — leave the screws snug, not gorilla-tight.

## Why this geometry (and what's deliberately *not* in v1)

- **Flat disc, not o-ring style or dimpled.** The simplest possible soft-mount. TPU 95A at 2 mm thickness gives enough compliance to damp the gyro-relevant 100–300 Hz band that a 5" build typically generates. More elaborate designs (o-ring contact, raised bosses, concentric grooves) come in v2 only if v1's gyro vibration shows up in ArduPilot's `PIDP.x/y/z` logs.
- **28 mm OD, not larger.** Same diameter as the motor base — no overhang, clean look, no risk of TPU getting nicked by a finger during install. If side cushioning becomes a thing, v2 can grow OD to 30 mm.
- **10 mm center bore.** Generous clearance for the EMAX bearing boss + airflow under the motor. The exact boss diameter on the EMAX ECO II 2207 is ~5–6 mm; 10 mm is overprovisioned but cheap.

## Files

| File | Role |
|---|---|
| `motor-soft-mount-v1.py` | source of truth (CadQuery) |
| `motor-soft-mount-v1.step` | exported STEP |
| `motor-soft-mount-v1.stl` | exported STL |
| `motor-soft-mount-v1-preview.svg` | top-down preview |
| `notes.md` | print orientation, slicer notes, lessons |

## Re-export

```bash
.venv/bin/python builds/v1/cad/motor-soft-mounts/motor-soft-mount-v1.py
```

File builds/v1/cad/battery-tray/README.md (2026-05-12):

# Battery tray

PETG cradle for the v1 LiPo (CNHL Black V2.0 1500mAh 4S 130C, `cat-008`). Mounts to the underside of the Source One V5 bottom carbon plate via 3M VHB tape, constrains the battery laterally with two side lips and one end stop, and passes a Velcro strap through two slots in the floor so the strap wraps over the top of the battery.

## Geometry summary

| Dimension | Value | Notes |
|---|---|---|
| Plate footprint | 79 × 40 mm | sized to battery 76 × 36 mm + 1 mm slop + lip thicknesses |
| Total height | 6 mm | 3 mm plate + 3 mm lip/end-stop walls |
| Cradle interior | 77 × 37 mm | with 3 mm-tall walls on 3 sides (XT60 end is open) |
| Strap slots | 5 × 20 mm × 2 | through-cuts at 18 mm and 59 mm from the closed end |
| Volume | ~9.8 cm³ | ≈ 12 g in PETG at 30 % infill |

## Battery dimensions (verified)

| Spec | Value | Source |
|---|---|---|
| Length | 76 mm | CNHL Black V2.0 1500mAh 4S 130C product listings, 2026-05-11 |
| Width | 36 mm | same |
| Height | 33 mm | same |
| Weight | 164 g | same |

Note: 33 mm height exceeds `cat-008`'s 30 mm envelope spec by 3 mm. The envelope was too tight; the actual pack fits the build but the catalog spec line is worth a refresh on the next catalog revision.

## Mounting interface

**Top face (up):** flat, prepared for **3M VHB tape**. Apply two strips (~half-width each, running long-axis) under the plate floor, between the strap slots. Press onto the underside of the Source One V5 bottom carbon plate.

No M3 bolt-through holes by design. Source One V5 brandings (TBS / RDQ / Pyrodrone) have slightly different bottom-plate hole patterns; VHB is frame-agnostic and removable for v2 iteration.

**Cradle (in):** battery slides in from the open (XT60) end, butts against the end-stop wall on the closed end. Velcro strap passes up through the rear slot, over the battery, and back down through the front slot.

## Why these choices

- **Sized to verified pack dimensions, not the catalog envelope.** The cat-008 envelope (≤90 × 35 × 30 mm) under-specs the actual 76 × 36 × 33 mm pack on two axes. Designing to envelope would have produced a tray the battery couldn't sit in.
- **One end stop, not two.** The XT60 lead has to exit somewhere; the open end is that side. A second end stop would require feeding the battery in through a slot.
- **PETG, not TPU.** The tray is rigid by design — it transfers the battery's mass through to the frame and keeps the pack from sliding under maneuver. Soft mounting belongs on the motors (cat: motor-soft-mounts), not the battery.
- **Two through-slots, not strap loops.** Slots cut clean through the plate. Loops would need extra TPU material on the underside and would interfere with the VHB adhesion plane.

## Files

| File | Role |
|---|---|
| `battery-tray-v1.py` | source of truth (CadQuery) |
| `battery-tray-v1.step` | exported STEP |
| `battery-tray-v1.stl` | exported STL |
| `battery-tray-v1-preview.svg` | isometric preview |
| `notes.md` | print orientation, slicer notes, lessons |

## Re-export

```bash
.venv/bin/python builds/v1/cad/battery-tray/battery-tray-v1.py
```

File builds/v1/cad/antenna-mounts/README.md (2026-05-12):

# Antenna mount

Holds the BetaFPV ELRS Lite V1.2 2.4GHz RX with Flat Antenna (`cat-006`) extended past the Source One V5 carbon frame edge for RF clearance to the operator.

## Quantity

**Quantity: 1.** The BetaFPV ELRS Lite RX (both Flat V1.2 and discontinued Tower variants) uses a single integrated SMD ceramic antenna soldered to the receiver PCB. No diversity pair. One module, one mount.

## SKU history

- v1 originally designed 2026-05-11 for the Tower variant (10×10×6mm).
- Tower variant went out of production at BetaFPV; build switched to Flat V1.2 (11×10×3mm) the same day. Three parameter values updated in the `.py` (`RX_W`, `RX_H`, slop unchanged); design intent unchanged.

## Geometry summary

| Dimension | Value | Notes |
|---|---|---|
| Total length | 52 mm | base center → far edge of cradle |
| Effective antenna offset | ~37 mm | base M3 hole → center of RX in cradle |
| Base | 15 × 15 × 3 mm | single M3 clearance hole at center |
| Boom | 22 × 8 × 4 mm | cantilever between base and cradle |
| Cradle | 15 × 14 × 7 mm outer | 12 × 11 × ∞ interior, walls 1.5 mm, open top and bottom |
| Volume | ~1.9 cm³ | ≈ 0.5 g in TPU 95A at typical 25% infill |

## Mounting interface

**Base (down):** single M3 clearance hole at base center. Designed to piggyback on a Source One V5 corner standoff — share the M3 bolt that holds the canopy down. Tighten the bolt, the antenna mount is held by friction against the canopy or top plate.

**Cradle (in):** friction-fit grip around the 11 × 10 × 3 mm RX module. 1 mm of clearance per axis (0.5 mm per side) — should hold the module firmly in TPU 95A without crushing it. If the fit is loose, reduce `RX_SLOP`; if it's too tight to insert, increase it.

**Top/bottom of cradle (open):** the integrated ceramic antenna points up through the open top. Solder pads on the RX face down through the open bottom. The 4-wire cable (5V, GND, RX, TX) exits the open bottom and routes back to the FC.

## Why this geometry

- **Boom length 22 mm.** Source One V5 top plate edge sits roughly 15–20 mm from a corner standoff; the boom extends the RX another ~10 mm past that edge. Empirically validates on first fit-check.
- **Cradle as a tube, not a box.** Open top is mandatory (the antenna sticks up); open bottom is intentional (cable exit + the print can run with no internal supports). TPU 95A wraps the RX on all 4 sides for friction grip.
- **Single M3 mount, not multi-bolt.** Two-bolt patterns would require a second standoff or a printed base wide enough to span two of them — adds mass and constrains canopy design. The TPU base + single bolt + friction against canopy is sufficient for a 0.47 g RX.
- **TPU 95A throughout.** The mount lives at the edge of the airframe and will be the first thing to hit grass / pavement / fence in any crash. PETG would snap. TPU bends and recovers.

## Files

| File | Role |
|---|---|
| `antenna-mount-v1.py` | source of truth (CadQuery) |
| `antenna-mount-v1.step` | exported STEP |
| `antenna-mount-v1.stl` | exported STL — direct slice in Bambu Studio |
| `antenna-mount-v1-preview.svg` | isometric preview, regenerable |
| `notes.md` | print orientation, slicer notes, lessons |

## Re-export

```bash
.venv/bin/python builds/v1/cad/antenna-mounts/antenna-mount-v1.py
```

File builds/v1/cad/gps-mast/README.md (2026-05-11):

# GPS mast

Holds the GNSS+compass module (`cat-005`, currently Holybro M10 GPS V2) ≥80 mm above the FC stack to clear high-current wiring and carbon RF shadow.

## Geometry summary

| Dimension | Value | Notes |
|---|---|---|
| Total height | 100 mm | base bottom → top platform top |
| Effective antenna height above base flange top | 97 mm | exceeds the 80 mm RF/EMI floor by 17 mm |
| Base flange | 38 × 38 × 3 mm | 4 × M3 clearance holes on 30.5 mm pattern |
| Shaft | 14 × 14 mm OD, 2 mm walls, 85 mm tall | `+Y` face open as a cable slot |
| Taper | 9 mm tall, 14×14 → 32×32 | 45° loft, prints support-free |
| Top platform | 32 × 32 × 3 mm | 4 × M3 clearance holes on 26 mm pattern |
| Volume | ≈ 17 cm³ | ≈ 6 g in PETG at 30% infill |

## Mounting interfaces

**Base (down):** 30.5 × 30.5 mm M3 pattern. Matches Source One V5 frame top plate / FC stack standard. Bolts pass through the canopy first if a printed canopy goes between mast and frame.

**Top (up):** 26 × 26 mm M3 pattern. **Assumed for Holybro M10 V2 — not yet measured against the physical part.** Verify on receipt; if wrong, edit `TOP_HOLE_PATTERN` and re-export. This is parametric so the change is one-line.

## Cable routing

Cable enters through the 10 × 10 mm hole in the base flange, travels up the hollow shaft, and exits through the 10 × 10 mm hole in the top platform to the GPS connector.

The `+Y` face of the shaft is fully open along its height. This is intentional: it means the cable does not have to be threaded through a closed tube during assembly, and the slot prints with no internal supports. The slot also lets the shaft be printed support-free upright.

## Why these choices

- **Square cross-section over round.** Easier to print upright (vertical walls), aligns naturally with M3 hole patterns, simpler parametric model.
- **Hollow with a slot, not solid.** Mass matters; an 80 mm solid PETG mast is wasted weight.
- **45° taper rather than a flat cantilever.** A 32 mm-wide platform overhanging a 14 mm shaft would need supports under the platform. The 9 mm taper is exactly tall enough to keep the underside at ≤45° and prints cleanly without supports.
- **PETG, not PA-CF.** RF-transparent (PA-CF would attenuate L-band GPS signals); structural strength isn't the constraint here, mass and antenna clearance are.

## Files

| File | Role |
|---|---|
| `gps-mast-v1.py` | Source of truth (CadQuery / Python). Edit this and re-export. |
| `gps-mast-v1.step` | STEP export — reusable in any CAD package. |
| `gps-mast-v1.stl` | Mesh export — direct slice in Bambu Studio. |
| `gps-mast-v1-preview.svg` | Quick isometric preview, regenerable from the `.py`. |
| `notes.md` | Print orientation, slicer settings, lessons learned. |

## Re-export

```bash
.venv/bin/python builds/v1/cad/gps-mast/gps-mast-v1.py
```

See `tools/cad/README.md` for the venv setup.

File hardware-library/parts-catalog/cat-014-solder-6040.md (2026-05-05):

# Solder Wire — 60/40 Leaded, 0.6mm

**Catalog ID:** cat-014
**Status:** active
**Last verified:** 2026-05-05

## Abstract spec

- 60% tin / 40% lead alloy (or lead-free SAC305 if jurisdiction requires)
- Rosin-core flux (1.0–2.2% flux content typical)
- 0.6mm diameter (good for FC pad work; 0.8mm acceptable for battery leads)
- 100g spool minimum

## Ranked SKUs

| Rank | Mfr part | Vendor | URL | Unit price | Notes |
|---|---|---|---|---|---|
| 1 | Kester 60/40 0.6mm 100g | Amazon | Amazon search "Kester 60/40 0.6mm" | ~$15 | reliable brand |
| 2 | MG Chemicals 60/40 0.6mm | Amazon | Amazon search | ~$12 | budget option |

## Reorder guidance

100g spool lasts a long time. Reorder when running low; not time-critical.

Suggested trigger: on hand ≤ 1. Suggested order qty: 1.

## Notes

- **Leaded solder is easier to learn with.** Lead-free flows worse, requires hotter iron, more skill. Use leaded for v1; switch to lead-free once you're comfortable if you care about RoHS/health.
- Wash hands after soldering. Don't eat at the soldering bench.
- Old/oxidized solder = bad joints. If your spool is >5 years old, replace it.

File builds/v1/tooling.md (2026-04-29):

# v1 — Tooling

**Status:** Ready to order
**Total estimated cost:** ~$235 (one-time)

This list assumes zero existing tools. If you already own some of these, skip them.

## Soldering

| # | SKU | Vendor | Qty | Unit | Notes |
|---|---|---|---|---|---|
| 1 | Pinecil V2 soldering iron | Pine Store / Amazon | 1 | $30 | Tiny, fast, PD-powered. Industry standard for budget. |
| 2 | USB-C PD power supply, 65W (if not already owned) | Amazon | 1 | $25 | Pinecil needs PD; phone chargers may not deliver enough. 65W is plenty. |
| 3 | Solder, lead-free or 60/40 leaded, 0.6mm rosin-core, 100g | Amazon | 1 | $15 | Leaded solders easier and cheaper to learn with. Lead-free is greener but harder. Your call. |
| 4 | Rosin flux paste | Amazon | 1 | $10 | A pea-sized amount makes joints flow. |
| 5 | Solder wick (desolder braid) | Amazon | 1 | $5 | For when joints go wrong. |
| 6 | Helping hands w/ magnifier + LED | Amazon | 1 | $25 | Critical for FC pad work. |
| 7 | Brass sponge tip cleaner | Amazon | 1 | $8 | Wet sponge wears tips down. Brass doesn't. |
| 8 | Heat-resistant silicone work mat | Amazon | 1 | $15 | Protects your bench, catches solder splash. |
| | | **Soldering subtotal** | | **$133** | |

**Soldering technique note for first time:** practice on cheap perfboard or a dead PCB before touching the FC. Get a feel for tinning the iron, applying flux, and how solder flows. Watch Joshua Bardwell's "How to Solder a Quadcopter" video — 30 min, the canonical primer.

## Measurement & test

| # | SKU | Vendor | Qty | Unit | Notes |
|---|---|---|---|---|---|
| 9 | AstroAI digital multimeter (or Klein MM320) | Amazon | 1 | $30 | Continuity, voltage, resistance. Don't need a Fluke for v1. |
| 10 | IR thermometer (gun-style) | Amazon | 1 | $20 | Check ESC/motor temps after first power-up and after flights. |
| | | **Measurement subtotal** | | **$50** | |

## Mechanical

| # | SKU | Vendor | Qty | Unit | Notes |
|---|---|---|---|---|---|
| 11 | Wera 2.5mm hex driver (or full set 1.5–3mm) | Amazon | 1 | $25 | Frame standoffs are M3 hex. Wera doesn't strip. |
| 12 | Wire strippers (16–26 AWG) | Amazon | 1 | $15 | Hakko CHP-170 or generic. |
| 13 | Side cutters (flush) | Amazon | 1 | $10 | For zip ties + wire trimming. |
| 14 | Needle-nose pliers (small) | Amazon | 1 | $10 | |
| 15 | Tweezers, ESD-safe, set of 3 | Amazon | 1 | $10 | For SMT work and small fasteners. |
| 16 | Rubber prop wrench (or M5 nut driver) | RDQ / Amazon | 1 | $5 | Don't strip prop nuts with pliers. |
| 17 | Loctite 243 (medium-strength threadlocker, blue) | Amazon | 1 | $8 | Motor screws. **NOT** Loctite Red — that's permanent. |
| | | **Mechanical subtotal** | | **$83** | |

## Safety

| # | SKU | Vendor | Qty | Unit | Notes |
|---|---|---|---|---|---|
| 18 | Safety glasses | Amazon | 1 | $5 | Soldering + first power-up. |
| 19 | LiPo bag | (in BOM, line 11) | — | — | |
| 20 | Class D fire extinguisher OR sand bucket | Local hardware store | 1 | $40 / $5 | Sand is cheaper and works. Bucket of dry sand near the LiPo charging area. |
| | | **Safety subtotal** | | **$45** | |

---

## Cost breakdown

| Category | Cost |
|---|---|
| Soldering | $133 |
| Measurement & test | $50 |
| Mechanical | $83 |
| Safety | $45 |
| **Tools subtotal** | **$311** |

(Note: rounded up vs. earlier $235 estimate — included threadlocker, IR thermometer, ESD tweezers, and rubber prop wrench which I'd initially assumed were optional. They're not.)

## What we're NOT buying for v1

These are real tools, but defer until proven needed:

- Bench power supply (~$80) — smoke stopper covers v1 needs.
- Hot-air rework station (~$80) — only if reflowing SMT components, which we're not.
- Oscilloscope — overkill for v1.
- Hakko FX-888D station ($110) — Pinecil is sufficient.
- Crimping tools for JST connectors — most peripherals come pre-wired.

## Workflow tips

- **Lay out a static workspace** before assembly. Soldering at a kitchen table with cats around is how parts disappear.
- **Photograph every step.** Drop photos in `builds/v1/assembly/photos/`. Future builds will reuse this as the assembly guide.
- **Tin everything before joining.** Pre-tin the wire, pre-tin the pad, then join. 80% of bad joints come from skipping this.

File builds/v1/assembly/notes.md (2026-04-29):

# v1 Assembly Notes

Fill in as you build. Photograph every step (drop into `./photos/`). Future builds reuse this as the assembly guide.

## Pre-assembly

- [ ] All parts received and accounted for against BOM.
- [ ] Tools laid out on workspace.
- [ ] Soldering iron tinned.
- [ ] Watched a 5" build walkthrough (Joshua Bardwell or Mark of UAVTech recommended).

## Stage 1 — Frame assembly (estimated 30 min)

Source One V5 instructions ship with the kit. Generally:

1. [ ] Unpack frame, verify part count.
2. [ ] Install motor mount screws into arms (don't tighten yet).
3. [ ] Apply Loctite 243 (blue) to motor screw threads.
4. [ ] Sandwich arms between top/bottom plates with standoffs at the four corners.
5. [ ] Tighten standoff screws hand-tight.

Photo: `photos/01-frame-assembled.jpg`
Notes:

## Stage 2 — Motor install (estimated 15 min)

1. [ ] Identify CW vs CCW motors (check labels and prop direction in motor spec sheet).
2. [ ] Install motors per the standard X-config:
   - Front-Right (M1): CCW prop, motor spins CW from above (standard ArduCopter)
   - Back-Right (M2): CW prop, motor spins CCW
   - Back-Left (M3): CCW prop, motor spins CW
   - Front-Left (M4): CW prop, motor spins CCW
3. [ ] Apply Loctite 243 to motor screws.
4. [ ] Tighten motor screws.
5. [ ] Verify motors spin freely by hand.

Note ArduCopter motor numbering convention is different from Betaflight. Refer to: https://ardupilot.org/copter/docs/connect-escs-and-motors.html

Photo: `photos/02-motors-installed.jpg`
Notes:

## Stage 3 — Soldering (estimated 90 min, first time)

⚠️ **Iron stays in the stand between joints. Eye protection on. Workspace clear of LiPos.**

### 3a. Tin everything first
- [ ] Tin the four motor pads on ESC.
- [ ] Tin the battery pad (positive and negative).
- [ ] Strip and tin the four motor wires.
- [ ] Strip and tin the battery lead wires.

### 3b. Solder motors to ESC
- [ ] Motor 1 → M1 pads (any wire to any pad — direction reversed in firmware later if wrong).
- [ ] Motor 2 → M2 pads.
- [ ] Motor 3 → M3 pads.
- [ ] Motor 4 → M4 pads.

### 3c. Solder battery lead with XT60
- [ ] Pre-tin XT60 cups before soldering wires.
- [ ] Heat shrink over each wire BEFORE soldering — easy to forget.
- [ ] Verify polarity: red to +, black to -.

### 3d. Multimeter check
- [ ] Continuity check: each motor wire to corresponding ESC pad.
- [ ] **No continuity** between battery + and -.
- [ ] **No continuity** between battery + and any motor wire.

Photo: `photos/03-stack-soldered.jpg`
Notes:

## Stage 4 — Stack mounting (estimated 20 min)

1. [ ] Mount FC + ESC stack to frame using vibration-damping rubber grommets (included in stack kit).
2. [ ] Connect FC to ESC via the included ribbon cable. Verify orientation per stack manual.
3. [ ] Verify USB-C port is accessible from outside the stack.

Photo: `photos/04-stack-mounted.jpg`
Notes:

## Stage 5 — Receiver install (estimated 20 min)

1. [ ] Solder RX power (5V, GND) and signal (TX of RX → RX of UART on FC) to FC.
2. [ ] ELRS receiver typically uses CRSF protocol on UART2 by default. Check FC pinout.
3. [ ] Mount RX with VHB tape on the bottom plate, antennas extending past the frame.
4. [ ] Antennas at 90° to each other for diversity.

Photo: `photos/05-rx-installed.jpg`
Notes:

## Stage 6 — GPS + compass install (estimated 20 min)

1. [ ] Print and install GPS mast (≥80mm tall).
2. [ ] Mount GPS module on top of mast with M3 screws or VHB.
3. [ ] Solder GPS wires to FC: 5V, GND, TX→RX (UART), RX→TX, SDA, SCL (for compass).
4. [ ] Verify compass orientation arrow points forward.

Photo: `photos/06-gps-mast.jpg`
Notes:

## Stage 7 — Telemetry radio install (estimated 15 min)

1. [ ] Mount SiK air radio on top plate or canopy with VHB.
2. [ ] Solder radio to FC UART (typically UART1 for telemetry).
3. [ ] Antenna extends vertically clear of frame.

Photo: `photos/07-telem-installed.jpg`
Notes:

## Stage 8 — Canopy + final assembly (estimated 20 min)

1. [ ] Install printed canopy over the stack.
2. [ ] Verify nothing pinches when closed.
3. [ ] Check all wires are strain-relieved (zip ties, hot glue at vibration points).
4. [ ] Install battery tray on bottom plate.
5. [ ] Install Velcro battery strap.

Photo: `photos/08-final-assembly.jpg`
Notes:

## Stage 9 — Pre-power-up check

⚠️ **Smoke stopper between battery and drone for first power-up.**

- [ ] Visual inspection: no loose wires, no exposed solder.
- [ ] Multimeter: no battery short.
- [ ] All M3 frame screws tight.
- [ ] **Props OFF.**

Ready for G1 (bench power-on).

---

## Issues encountered (running log)

| Stage | Issue | Resolution |
|---|---|---|
|  |  |  |

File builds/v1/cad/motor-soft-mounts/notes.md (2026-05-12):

# Print notes — motor soft-mount

## Orientation

Print **flat on the bed**, pad face down. No supports, no overhangs (it's a disc).

Pack 4 copies onto the bed for a single print job — each is 28 mm OD and the parts are independent. Bed plate easily fits all 4 with brim spacing.

## Filament and slicer settings (Bambu P2S, 0.4 mm stock nozzle)

TPU 95A defaults from `builds/v1/cad/README.md` apply unmodified.

| Setting | Value |
|---|---|
| Filament | Bambu TPU 95A HF, black (`cat-010`) |
| Nozzle | 230 °C |
| Bed | 50 °C |
| Layer height | 0.2 mm |
| Walls | 3 |
| Top/bottom layers | 4 |
| Infill | 25 % gyroid |
| Print speed | ≤ 30 mm/s |
| Retraction | minimize |
| Supports | None |
| Brim | 3 mm (small part — extra adhesion margin) |

**External-spool feed required.** Bambu TPU 95A HF is not AMS-compatible (per `cat-010`).

Estimated print time: ~5 min per pad → ~20 min for the v1 set of 4.

## After-print fit-check

When motors and frame arrive:

1. M3 SHCS passes through the 3.4 mm holes without forcing.
2. Pattern aligns to motor's M3 holes and arm's M3 holes (both should be 16 × 16 mm).
3. Motor base sits flush on the pad (pad's 28 mm OD matches motor base).
4. Bearing boss / shaft on motor underside clears the 10 mm center bore.
5. With all 4 M3 screws hand-tight, motor sits firmly on the arm with the TPU slightly compressed (1.8 mm gap, down from 2.0 mm nominal). No wobble.

## Known assumptions to verify on first physical fit

- **Hole pattern 16 × 16 mm.** Per `cat-003` abstract spec, both the EMAX ECO II 2207 and Source One V5 arms use this pattern. Verify on receipt — some 2207 motors are 19 × 19 mm and some arms support both. If the actual motor or arm uses 19 × 19, change `HOLE_PATTERN` to 19 in the `.py` and re-export.
- **Motor base 28 mm OD.** Typical for 2207-class motors. Measure with calipers when motors arrive; if smaller, the pad will overhang slightly (cosmetic, not functional). If larger, the pad will undersize and may not fully cushion — reduce `MOUNT_OD` to match.
- **Bearing boss < 10 mm.** Generous. Verify by visual inspection that nothing protruding from the motor base hits the pad inside the 10 mm bore.

## Lessons

(Empty — fill in after the first print.)

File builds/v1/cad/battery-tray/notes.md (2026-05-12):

# Print notes — battery tray

## Orientation

Print **flat on the bed, plate side down**. Lips and end-stop wall face up. No supports.

The strap slots are vertical holes through the plate — no bridging required since they're cut all the way through. The lips and end stop are short (3 mm tall) and prismatic, so no overhangs.

## Filament and slicer settings (Bambu P2S, 0.4 mm stock nozzle)

PETG defaults from `builds/v1/cad/README.md` apply unmodified. Starting recipe:

| Setting | Value |
|---|---|
| Filament | Bambu PETG Basic, black (`cat-009`) |
| Nozzle | 240 °C |
| Bed | 70 °C |
| Layer height | 0.2 mm |
| Walls | 4 |
| Top/bottom layers | 5 |
| Infill | 30 % gyroid |
| Supports | **None** |
| Brim | 5 mm |

Estimated print time: ~1 h per `requirements.md` §8. The plate is the bulk of the print time.

## After-print fit-check

When the LiPo pack arrives:

1. Battery slides into the cradle from the open (XT60) end with ~0.5 mm clearance per side. Should not be tight.
2. End-stop wall fully stops the battery at the closed end (the XT60 lead has clearance through the open end).
3. Velcro strap (15–20 mm wide) passes through both slots without forcing.
4. With strap tightened, the battery is held firmly against the floor with no lateral wobble.

## VHB mounting procedure

When the frame's bottom plate arrives:

1. Clean both surfaces with isopropyl alcohol; let dry.
2. Apply two strips of 3M VHB (`cat: solder-6040` adjacent — VHB is uncataloged but in the BOM hardware list) to the **top face** of the tray, running long-axis, **between** the strap slots (do not cover the slots).
3. Press tray firmly to the underside of the frame's bottom carbon plate. Hold under firm pressure for 60 s.
4. Let cure 24 h before flying — VHB reaches full bond strength slowly.

## Known assumptions to verify on first physical fit

- **Battery dimensions: 76 × 36 × 33 mm.** Verified against multiple CNHL Black V2.0 1500mAh 4S 130C distributor listings 2026-05-11. Verify on receipt with calipers — pack-to-pack manufacturing variance can be ±1–2 mm.
- **No M3 bolt-through.** Reconsider only if the VHB mount turns out to be unreliable in flight. Probably won't.
- **Strap-slot positions (18 and 59 mm from closed end).** Chosen for roughly quarter/three-quarter placement along the battery. If the strap doesn't sit well, adjust `SLOT_MARGIN` in the `.py`.

## Lessons

(Empty — fill in after the first print.)

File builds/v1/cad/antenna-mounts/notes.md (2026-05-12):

# Print notes — antenna mount

## Orientation

Print **flat on the bed** — base face down. The entire part is essentially a flat L-shaped extrusion; no overhangs steeper than the cradle's 4 vertical walls. No supports needed.

The cradle's open top and open bottom both face the Z-axis when printed flat (open top → +Z; open bottom → bed). The 11×11mm internal pocket of the cradle prints as a vertical hole — no bridging.

## Filament and slicer settings (Bambu P2S, 0.4 mm stock nozzle)

TPU 95A defaults from `builds/v1/cad/README.md` apply unmodified. Starting recipe:

| Setting | Value |
|---|---|
| Filament | Bambu TPU 95A HF, black (`cat-010`) |
| Nozzle | 230 °C |
| Bed | 50 °C |
| Layer height | 0.2 mm |
| Walls | 3 |
| Top/bottom layers | 4 |
| Infill | 25 % gyroid |
| Print speed | ≤30 mm/s |
| Retraction | minimize (1 mm or less) |
| Supports | **None** |
| Brim | 5 mm (small footprint + TPU benefits from extra bed adhesion) |

**External-spool feed required.** Bambu TPU 95A HF is **not** AMS-compatible (per `cat-010`). Load from the side spool holder on the P2S, not the AMS.

Estimated print time: ~20 min per part (from `requirements.md` §8). Tiny part, low mass.

## After-print fit-check

Before the canopy + RX are wired up:

1. M3 screw drops through the base hole without forcing. PETG-style hole sizing applies (3.4 mm hole + ~0.5% shrinkage).
2. The 11 × 10 × 3 mm BetaFPV ELRS Lite V1.2 RX (when received) slides into the cradle with light friction. Should hold the RX during gentle shaking but pop free with deliberate finger pressure. If too loose: reduce `RX_SLOP` in the `.py` and re-export. If too tight: increase it.
3. The 4-wire RX cable can pass through the open bottom of the cradle without getting pinched.

## Known assumptions to verify on first physical fit

- **RX module dimensions: 11 × 10 × 3 mm** (BetaFPV ELRS Lite V1.2 Flat). Confirmed from BetaFPV's product page on 2026-05-11. Verify on receipt — RFI shielding or solder pads can add a fraction of a millimeter that the spec sheet glosses over.
- **Source One V5 corner-standoff M3 pattern.** Standard 30.5 mm or arm-corner spacing varies slightly across Source One V5 manufacturer brandings (TBS / RDQ / Pyrodrone). The single center M3 hole is forgiving — anywhere a corner bolt sticks up, this mounts on it.
- **22 mm boom length.** Eyeballed from the Source One V5 top plate dimensions; may want to grow to 28–30 mm if the carbon edge ends up closer to the corner than I expect. Trivial parametric edit.

## Lessons

(Empty — fill in after the first print.)

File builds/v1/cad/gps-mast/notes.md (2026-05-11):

# Print notes — gps-mast

## Orientation

Print **upright**, base flange flat on the bed.

- All vertical walls of the shaft print without supports.
- The 45° taper from shaft to top platform stays at or under the support-free angle (Bambu defaults are fine).
- The `+Y` cable slot is a vertical opening, so it doesn't need bridging.

Do not lay it on its side. The square cross-section becomes a horizontal overhang and one of the wall faces ends up unsupported.

## Filament and slicer settings (Bambu P2S, 0.4 mm stock nozzle)

PETG defaults from `builds/v1/cad/README.md` apply unmodified. Starting recipe:

| Setting | Value |
|---|---|
| Filament | PETG, generic |
| Nozzle | 240 °C |
| Bed | 70 °C |
| Layer height | 0.2 mm |
| Walls | 4 |
| Top/bottom layers | 5 |
| Infill | 30 % gyroid |
| Supports | **None** (design is support-free) |
| Brim | 5 mm (small base footprint, prevents detachment on a 100 mm-tall print) |

Estimated print time: ~30 min per the requirements doc; verify on first slice.

## After-print fit-check

Before unboxing the rest of the build:

1. M3 screws fit through both the base and top hole patterns without forcing.
2. Mounting pattern aligns with the Source One V5 top plate (base) and the GPS module (top).
3. GPS UART cable + connector pass through the 10×10 mm channel.
4. `+Y` slot is wide enough to lay the cable in without flexing the shaft.

## Known assumptions to verify on first physical fit

- **Top hole pattern is 26 mm.** Assumed from typical Holybro M10 module pinouts; not measured. If wrong, edit `TOP_HOLE_PATTERN` in the `.py` and bump to `gps-mast-v2`.
- **Base hole pattern is 30.5 mm.** Standard FC stack pattern, also used by Source One V5 top plate. Verified from the requirements doc, not measured against the actual frame.
- **PETG creep is acceptable for this part.** Mast lives away from heat sources; ambient operation only. PETG creep onset is around 75 °C, well above any temperature this part sees.

## Lessons

(Empty — fill in after the first print.)

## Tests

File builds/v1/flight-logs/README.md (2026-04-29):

# v1 — Flight Logs

One folder per flight. Naming: `<YYYY-MM-DD>_<flight-id>_<short-description>/`.

## Per-flight folder contents

```
2025-12-04_001_first-tethered-hover/
├── notes.md                  # written before + after the flight
├── mission.waypoints         # if it was an AUTO mission
├── log.bin                   # raw ArduPilot dataflash log (gitignored if >10MB)
├── log.csv                   # converted log (committed)
├── log.tlog                  # MAVLink telemetry log (committed)
├── pre-flight.params         # exact param dump used for this flight
└── photos/                   # any post-flight photos (damage, screenshots, etc.)
```

## notes.md template

```markdown
# Flight 001 — first tethered hover

**Date:** 2025-12-04
**Location:** [park name]
**Pilot:** [your name]
**Observer:** [name]
**Wind:** ~3 m/s NW
**Battery:** CNHL #1, started 16.78V, ended 16.12V

## Plan

[what we intended to do]

## Result

[what actually happened]

## Issues

[any anomalies, even minor]

## Action items

[anything to fix before next flight]

## Gates passed

- [ ] G6: Tethered hover
```

## Log conversion

Raw `.bin` → `.csv`:
- Mission Planner: DataFlash Logs → "Create Matlab File" or "Pull This Log via MavLink".
- Or `mavlogdump.py` from pymavlink.

We commit the `.csv` and `.tlog` for grep-ability and small size; `.bin` is gitignored unless we add Git LFS later.

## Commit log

2026-05-05 update v1 BOM based on procurement research
2026-05-11 v1 gps-mast design
    [gps-mast-v1.step, gps-mast-v1.stl]
2026-05-12 update ELRS to flat antenna
2026-05-12 v1 antenna-mount design
    [antenna-mount-v1.step, antenna-mount-v1.stl]
2026-05-12 v1 battery-tray design
    [battery-tray-v1.step, battery-tray-v1.stl]
2026-05-12 update v1 battery dimensions
2026-05-12 v1 motor-soft-mount design
    [motor-soft-mount-v1.step, motor-soft-mount-v1.stl]
